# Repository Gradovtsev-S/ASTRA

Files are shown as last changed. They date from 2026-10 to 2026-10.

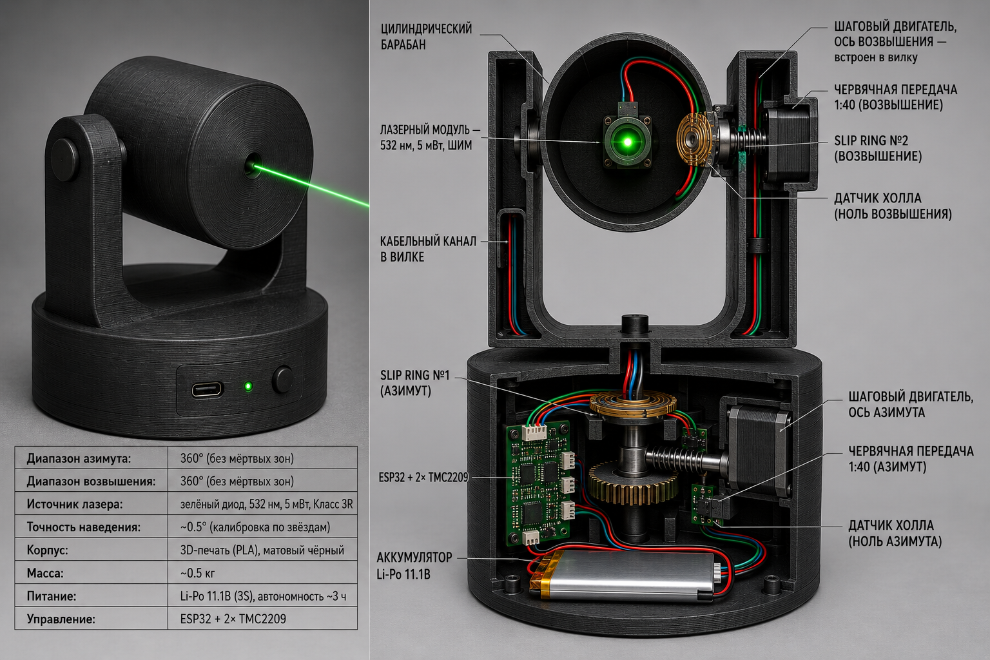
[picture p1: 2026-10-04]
docs/latex/laser_tracker.png

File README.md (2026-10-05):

# ASTRA

**Autonomous Stellar Targeting Remote-access Apparatus**

Репозиторий проекта **StarTracker** — автоматизированного лазерного звёздного трекера, который наводит зелёный лазер (532 нм, 5 мВт) на любую звезду, планету или иной небесный объект по команде из Telegram-бота.

> Проект выполняется в рамках курса «Введение в цифровое производство. Практикум цифрового производства», ФАКТ МФТИ, Долгопрудный, 2026.

---

## Команда

| Участник | Группа |
|---|---|
| Градовцев Святослав Алексеевич | Б03-503 |
| Коломоец Александр Анатольевич | Б03-503 |
| Минаева Полина Игоревна | Б03-502 |

---

## О проекте

Устройство на двухосной поворотной платформе определяет своё положение и ориентацию, рассчитывает положение небесного тела и наводит на него лазер. Управление — через Telegram-бот по Wi-Fi. Вся логика выполняется на одном микроконтроллере ESP32.

**Ключевые характеристики**

| Параметр | Значение |
|---|---|
| Диапазон азимута | 360° непрерывно |
| Диапазон возвышения | 360° непрерывно |
| Точность наведения | 0.5–2° |
| Лазер | зелёный 532 нм, 5 мВт, класс 3R |
| Управление | Telegram-бот |
| Автономность | 3 часа |
| Корпус | 3D-печать PLA/PETG + лазерная резка (фанера/акрил) |

**Элементная база:** ESP32, 2× TMC2209 StepStick, RTC DS3231, GPS Neoway G7A, IMU BMI160, магнитометр GY-511, 2× NEMA17, 2× токосъёмное кольцо (slip ring ∅12 мм, 6 каналов), 2× Li-Ion LP385590 (2300 мАч, 3S), DC-DC MP1584, лазерный модуль 5 мВт (TTL), MOSFET IRLZ44N, датчики Холла A3144E на LM393.

---

## Принцип работы

1. GPS и RTC дают положение установки и время UTC.
2. BMI160 измеряет наклон основания (крен и тангаж).
3. Магнитометр определяет направление нуля монтировки относительно севера (с поправкой на магнитное склонение).
4. По имени объекта рассчитываются его азимут и высота над горизонтом (Astronomy Engine, для звёзд — собственный каталог).
5. Углы переводятся в систему монтировки и отправляются на моторы.
6. Лазер включается только когда цель достигнута и все данные достоверны.

---

## Архитектура репозитория

```
ASTRA/
├── README.md
├── CONTRIBUTING.md
├── .gitignore
├── .gitattributes
│
├── CAD/                              # CAD-модели (SolidWorks)
│   └── Base/                         # Узел 1 — неподвижное основание
│       ├── Base.SLDPRT
│       ├── docs/
│       │   ├── StarTracker_Summary_v2.md     # Итоговый конструктив v2
│       │   └── StarTracker_DesignNotes.md    # Почему конструкция сделана именно так
│       └── simulation/               # Файлы расчёта прочности (SolidWorks Simulation)
│
├── docs/                             # Документация проекта
│   ├── project_proposal.md           # Цель, функционал, задачи, аналоги, элементная база
│   ├── project_plan.md               # Конструкция, схема соединений, распиновка ESP32,
│   │                                 #   алгоритмы, этапы, BOM, риски
│   ├── course_materials/             # Методические материалы курса
│   └── latex/                        # Проектное предложение в LaTeX (+ собранный PDF)
│
├── firmware/                         # Прошивка ESP32 (C/C++)
│   ├── platformio.ini                # Конфигурация PlatformIO
│   ├── data/
│   ├── src/
│   │   ├── config.h
│   │   ├── secrets.example.h         # Шаблон: копия секретов без значений
│   │   ├── secrets.h                 # Wi-Fi и токен Telegram (не коммитится)
│   │   ├── main.cpp                  # setup(): инициализация, loop(): главный цикл
│   │   │
│   │   ├── sensors/                  # Датчики
│   │   │   ├── gps.*                 # GPS Neoway G7A (UART) + RTC DS3231 (I2C)
│   │   │   ├── gyro_accel.*          # BMI160: крен и тангаж основания
│   │   │   └── mag_compass.*         # GY-511: истинный азимут нуля монтировки
│   │   │
│   │   ├── actuators/                # Исполнительные устройства
│   │   │   ├── motors.*              # 2× NEMA17 через TMC2209, поиск нуля по Холлу
│   │   │   └── laser.*               # Лазер с защитой по таймеру
│   │   │
│   │   └── logic/                    # Расчёт наведения
│   │       ├── handler.*             # Имя объекта + место/время/ориентация -> углы монтировки
│   │       ├── adapter.*             # Данные датчиков -> входные типы handler
│   │       ├── star_catalog.*        # Звёзды по имени -> RA/Dec (J2000)
│   │       └── astronomy.*           # Библиотека Astronomy Engine (не редактируется)
│   │
│   └── test/
│       └── motor_test.ino            # Тест шаговых двигателей
│
├── references/
│   └── modeling_links.txt            # Ссылки по креплению подшипников и ГОСТам на канавки
│
└── sketches/                         # Эскизы конструкции
```

### Описание разделов

| Папка | Назначение |
|---|---|
| **CAD** | CAD-модели механики по узлам. Рядом с моделью лежит документация с обоснованием решений и расчёты. |
| **docs** | Постановка задачи, план, анализ аналогов, BOM, риски. LaTeX-версия для оформления и сдачи. |
| **firmware** | Прошивка ESP32 и тестовые скетчи. |
| **references** | Ссылки и заметки, использованные при проектировании. |
| **sketches** | Эскизы конструкции. |

---

## Безопасность лазера

- после `laser_init` лазер выключен;
- включается только при `status == Ok`, достигнутой цели и достоверных данных датчиков;
- любая потеря данных выключает лазер;
- вторая линия защиты — автоотключение по таймеру `LASER_MAX_ON_MS` внутри `laser.cpp`.

---

## Используемые технологии

- **Железо:** ESP32, TMC2209, NEMA17, GPS Neoway G7A, BMI160, GY-511, DS3231
- **CAD:** SolidWorks
- **Прошивка:** C/C++, PlatformIO (Arduino framework для ESP32), Astronomy Engine
- **Интерфейс:** Telegram Bot API
- **Документация:** Markdown, LaTeX

---

## Сборка и запуск

1. Установить VS Code и расширение PlatformIO IDE, открыть папку `firmware`.
2. Скопировать `firmware/src/secrets.example.h` в `firmware/src/secrets.h`
   и вписать данные Wi-Fi и токен бота.
3. Заполнить значения в `firmware/src/config.h` (пины, механика, склонение).
4. Собрать (`pio run` или кнопка Build) и прошить ESP32.

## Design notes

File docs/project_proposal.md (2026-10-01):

# StarTracker

### Автоматизированный лазерный звёздный трекер

**Московский ордена Трудового Красного Знамени**  
**Физико-технический институт (Национальный исследовательский университет)**  
Факультет аэрофизики и космических исследований

Введение в цифровое производство. Практикум цифрового производства.

**Долгопрудный, 2026**

---

## Название проекта

**StarTracker** — автоматизированный лазерный звёздный трекер для наведения на небесные объекты.

---

## Ментор

Провоторов Павел Владимирович

---

## Команда

| Участник | Группа | Telegram | Телефон |
|---|---|---|---|
| Градовцев Святослав Алексеевич | Б03-504 | @svt_gradov | +7 999 248-86-97 |
| Коломоец Александр Анатольевич | Б03-504 | @AlexanderKolomoets | +7 961 213-93-21 |
| Минаева Полина Игоревна | Б03-504 | @Polina_Minaewa | +7 910 855-06-48 |

---

## Цель проекта

Создать автоматизированное устройство для наведения лазерного указателя (5 мВт, 532 нм) на любую звезду, планету или иной небесный объект по выбору пользователя, обеспечивающее полный охват небосвода по азимуту и возвышению (360° по каждой оси без мёртвых зон), автономную работу не менее 3 часов и точность наведения 0.5–2° после калибровки по звёздам, с управлением через Telegram-бот по Wi-Fi.

---

## Описание функционала

Компактный звёздный трекер на двухосной поворотной платформе. Устройство получает данные о местоположении пользователя через GPS-модуль, определяет ориентацию относительно горизонта при помощи гироскопа и акселерометра, и на основе астрономических расчётов наводит лазер на любой выбранный небесный объект.

### Основные функции

- Автоматическое определение координат пользователя (GPS NEO-6M)
- Определение угла наклона и ориентации устройства (IMU MPU-6050)
- Расчёт положения небесных тел в реальном времени (библиотека Astronomy Engine, C)
- Наведение лазера на выбранный объект по двум осям (азимут + возвышение, 360° каждая)
- Управление через Telegram-бот по Wi-Fi
- Калибровка устройства перед использованием (датчики Холла, процедура star alignment)

### Дополнительный функционал

- Режим автоматического сопровождения объекта (пересчёт позиции каждые 10 с)
- Встроенный каталог ~200 объектов во flash ESP32 + Yale Bright Star Catalog (9110 звёзд) в SPIFFS
- Ручной ввод координат как fallback при отсутствии GPS-сигнала
- RTC DS3231 для точного хранения времени при потере GPS

### Целевые характеристики

| Параметр | Значение |
|---|---|
| Диапазон азимута | 360° непрерывно (без мёртвых зон) |
| Диапазон возвышения | 360° непрерывно (через зенит) |
| Точность наведения | 0.5–2° (с калибровкой по звёздам) |
| Угловое разрешение | 0.0028°/шаг |
| Лазер | Зелёный 532 нм, 5 мВт, класс 3R |
| Управление | Telegram-бот по Wi-Fi (ESP32) |
| Питание | АКБ 3S Li-Ion 11.1В / 3000 мАч |
| Автономность | ≥ 3 часа |
| Масса | ~1.1–1.3 кг |
| Габариты | ~150×150×190 мм (цилиндр) + основание ∅220 мм |
| Корпус | 3D-печать PLA/PETG, матовый чёрный |

---

## Конструкция

### Форм-фактор
Цилиндрический корпус (~150×150×190 мм) на круглом основании (∅220 мм), установленный в U-рамку на поворотной платформе. Внешне напоминает PTZ-камеру на поворотной платформе.

### Две оси вращения

**Ось азимута (Z) — нижнее основание:**
- Диапазон: 360° непрерывно
- Привод: NEMA17 + червячная пара 1:40 (самоторможение)
- Slip Ring #1 в центре основания — передаёт питание и сигналы при любом угле

**Ось возвышения (Y) — горизонтальная ось U-рамки:**
- Диапазон: 360° непрерывно (цилиндр делает «сальто» через зенит)
- Привод: NEMA17 + червячная пара 1:40
- Slip Ring #2 в левой опоре — передаёт питание и сигнал к лазеру
- При переходе за 90° (зенит): платформа разворачивается на 180°, лазер идёт «за голову»

---

## Задачи проекта

1. Выбор элементной базы и архитектуры системы
2. Разработка CAD-моделей корпуса и поворотной платформы (SolidWorks)
3. Проектирование механизма наведения лазера (двухосная монтировка, червячные передачи)
4. Создание электронной схемы устройства
5. Разработка собственной печатной платы (KiCad, JLCPCB)
6. Интеграция GPS-модуля, гироскопа и управляющего контроллера
7. Разработка прошивки микроконтроллера (Arduino/ESP-IDF, Astronomy Engine)
8. Реализация Telegram-бота (`/find`, `/track`, `/stop`, `/calibrate`, `/status`)
9. Производство деталей методом 3D-печати и лазерной резки
10. Сборка и тестирование устройства
11. Калибровка системы и проверка точности наведения (star alignment по 2–3 звёздам)

---

## Анализ существующих аналогов

### 1. Celestron StarSense Explorer
Система использует смартфон для определения положения звёздного неба и помощи в наведении телескопа.

**Преимущества:** удобство использования, автоматический поиск объектов.  
**Недостатки:** высокая стоимость, необходимость использования телескопа, отсутствие лазерного наведения.  
https://www.celestron.com/pages/starsense-explorer

### 2. DIY OpenAstroTracker
Open-source проект автоматизированного трекера для астрофотографии на Arduino.

**Преимущества:** открытый исходный код, возможность самостоятельной сборки.  
**Недостатки:** сложность настройки, отсутствие удобного пользовательского интерфейса, не предназначен для лазерного наведения.  
https://openastrotech.com

**Отличие StarTracker от аналогов:** автономная работа с GPS и гироскопической системой, удобное управление через Telegram-бот, полный охват небосвода без мёртвых зон по обеим осям, компактный корпус с лазерным указателем вместо телескопической оптики.

---

## Эскиз проекта

Устройство состоит из цилиндрического корпуса с лазерным модулем, установленного в U-рамку на двухосной поворотной платформе. Нижнее основание содержит привод азимута и аккумулятор, U-рамка несёт привод возвышения и оба slip ring для непрерывного вращения по обеим осям.

*(Эскиз прилагается отдельным файлом)*

---

## Элементная база

| Компонент | Модель | Кол-во |
|---|---|---|
| Микроконтроллер | ESP32 DevKit v1 | 1 |
| Драйвер шаговых двигателей | TMC2209 StepStick | 2 |
| Шаговый двигатель | NEMA17, 40 мм, 1.8°/шаг | 2 |
| GPS-модуль | NEO-6M с антенной | 1 |
| Гироскоп и акселерометр | MPU-6050 (IMU, I2C) | 1 |
| Часы реального времени | DS3231 (RTC, I2C) | 1 |
| Лазерный модуль | Зелёный 532 нм, 5 мВт, TTL | 1 |
| MOSFET-ключ лазера | IRLZ44N | 2 |
| Токосъёмное кольцо | Slip Ring 12 мм, 6 каналов | 2 |
| Аккумулятор | 18650 Li-Ion 3S, 3000 мАч + BMS | 1 |
| DC-DC преобразователь | MP1584, 11.1В → 5В | 2 |
| Подшипники | 608ZZ | 4 |
| Датчики нулевого положения | Датчик Холла A3144 | 2 |
| Печатная плата | Заказная PCB (KiCad → JLCPCB) | 1 |
| Корпусные элементы | PLA/PETG, 3D-печать; фанера 4 мм, лазерная резка | — |

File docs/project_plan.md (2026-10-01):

# StarTracker — Итоговый план реализации

---

## Концепция устройства

**StarTracker** — автоматизированный лазерный звёздный трекер на двухосной монтировке.
Устройство наводит зелёный лазер (5 мВт) на любую звезду, планету или небесный объект
по выбору пользователя через Telegram-бот.

---

## Конструкция (финальный вариант)

### Форм-фактор
Цилиндрический корпус (~150×150×190 мм, масса ~1.1–1.3 кг) на круглом основании
(∅300 мм). Внешне напоминает PTZ-камеру / прожектор на поворотной платформе.

### Две оси вращения

**Ось азимута (Z) — нижнее основание:**
- Диапазон: 360° непрерывно
- Привод: NEMA17 + червячная пара 1:40 (самоторможение, не нужен удерживающий ток)
- Slip Ring #1 в центре основания — передаёт питание и сигналы наверх при любом угле

**Ось возвышения (Y) — горизонтальная ось U-рамки:**
- Диапазон: 360° непрерывно (цилиндр делает «сальто» через зенит)
- Привод: NEMA17 + червячная пара 1:40
- Slip Ring #2 в левой опоре — передаёт питание и сигнал к лазеру
- При переходе за 90° (зенит): платформа разворачивается на 180°, лазер идёт «за голову»

### Внутренняя компоновка цилиндра
| Компонент | Позиция | Примечание |
|---|---|---|
| Лазерный модуль 5 мВт | Передняя стенка | TTL-управление через MOSFET IRLZ44N |
| ESP32 + собственная PCB | Центр | Wi-Fi, управление всей системой |
| АКБ 3S Li-Ion 3000 мАч | Нижняя часть | ~3 часа автономной работы |
| GPS NEO-6M | Верхняя часть | Антенна выведена наружу или в крышку |
| IMU MPU-6050 | Рядом с PCB | I2C, коррекция наклона основания |
| RTC DS3231 | На PCB | Точное время при потере GPS |
| DC-DC конвертер | На PCB | 11.1В → 5В и 3.3В |

### U-рамка
Алюминий или PETG-печать. Две вертикальные стойки + поперечина сверху. В стойках —
подшипники оси возвышения. Крепится к поворотной платформе болтами.

### Корпус
- Цилиндр и основание: PLA/PETG, 3D-печать
- Элементы жёсткости: лазерная резка из фанеры 4 мм или акрила
- Крышка цилиндра: съёмная, на защёлках — для доступа к электронике

---

## Схема электрических соединений

### Питание (три уровня)
```
АКБ 3S Li-Ion (11.1В)
├── TMC2209 #1 VM (12В) — мотор азимута
├── TMC2209 #2 VM (12В) — мотор возвышения
└── DC-DC MP1584 → 5В
    ├── ESP32 (VIN)
    ├── Лазер (через MOSFET)
    └── ESP32 3V3 pin → MPU-6050, DS3231, датчики Холла
```

### Распиновка ESP32
| GPIO | Функция | Куда |
|---|---|---|
| GPIO16 | UART2 RX | GPS NEO-6M TX |
| GPIO17 | UART2 TX | GPS NEO-6M RX |
| GPIO21 | I2C SDA | MPU-6050 + DS3231 |
| GPIO22 | I2C SCL | MPU-6050 + DS3231 |
| GPIO2 | STEP | TMC2209 #1 (азимут) |
| GPIO4 | DIR | TMC2209 #1 (азимут) |
| GPIO5 | EN | TMC2209 #1 (азимут) |
| GPIO18 | STEP | TMC2209 #2 (возвышение) |
| GPIO19 | DIR | TMC2209 #2 (возвышение) |
| GPIO23 | EN | TMC2209 #2 (возвышение) |
| GPIO1 | UART0 TX | TMC2209 #1 и #2 PDN_UART (один провод, разные адреса) |
| GPIO25 | PWM/GPIO | Gate MOSFET IRLZ44N (лазер) |
| GPIO34 | Input | Датчик Холла — ноль азимута |
| GPIO35 | Input | Датчик Холла — ноль возвышения |

### Управление лазером
```
GPIO25 → резистор 1 кОм → Gate IRLZ44N
Source IRLZ44N → GND
Drain IRLZ44N → GND лазера
+5В → VCC лазера
```

---

## Математика и алгоритмы

### Астрорасчёт (библиотека Astronomy Engine, C)
```c
// Планеты:
astro_time_t t = Astronomy_MakeTime(year, month, day, hour, min, sec); // UTC!
astro_observer_t obs = Astronomy_MakeObserver(lat, lon, elev);
astro_equatorial_t eq = Astronomy_Equator(BODY_JUPITER, &t, &obs,
                                           EQUATOR_OF_DATE, ABERRATION);
astro_horizon_t hor = Astronomy_Horizon(&t, &obs, eq.ra, eq.dec, REFRACTION_NORMAL);
double az  = hor.azimuth;   // 0–360°, от севера
double alt = hor.altitude;  // градусы над горизонтом

// Звёзды из каталога:
astro_horizon_t hor = Astronomy_Horizon(&t, &obs,
    18.615,  // RA в часах (Вега)
    38.783,  // Dec в градусах
    REFRACTION_NORMAL);
```

### Коррекция наклона (IMU MPU-6050)
```c
// Углы наклона из акселерометра
float roll  = atan2(ay, az) * 180.0 / M_PI;
float pitch = atan2(-ax, sqrt(ay*ay + az*az)) * 180.0 / M_PI;

// Complementary filter (каждые 10 мс)
roll  = 0.98 * (roll  + gx * 0.01) + 0.02 * atan2(ay, az) * 180.0 / M_PI;
pitch = 0.98 * (pitch + gy * 0.01) + 0.02 * atan2(-ax, ...) * 180.0 / M_PI;

// Поворот вектора для компенсации наклона
double x = cos(alt_r) * sin(az_r);
double y = cos(alt_r) * cos(az_r);
double z = sin(alt_r);
// ... вращение через матрицы крена и тангажа ...
double az_corr  = atan2(x2, y1) * 180.0 / M_PI;
double alt_corr = asin(z2)      * 180.0 / M_PI;
```

### Логика 360° по возвышению
```c
// Если объект «за зенитом» — цилиндр делает сальто
if (alt_target > 90.0) {
    alt_motor = 180.0 - alt_target; // лазер смотрит назад
    az_motor  = az_target + 180.0;  // платформа разворачивается
    if (az_motor >= 360.0) az_motor -= 360.0;
} else {
    alt_motor = alt_target;
    az_motor  = az_target;
}
```

### Перевод углов в шаги моторов
```c
// NEMA17 (200 шаг/об) + червяк 1:40 + микрошаг ×16
// Итого: 200 × 40 × 16 = 128 000 шагов/оборот
// Разрешение: 360° / 128000 = 0.0028°/шаг

int az_steps  = (az_motor  / 360.0) * 128000;
int alt_steps = (alt_motor / 360.0) * 128000;
stepper_az.moveTo(az_steps);
stepper_alt.moveTo(alt_steps);
```

---

## Каталог звёзд (встроен во flash ESP32)

```c
typedef struct { const char* name; double ra; double dec; } StarEntry;

const StarEntry catalog[] = {
    {"Vega",        18.615,  38.783},
    {"Sirius",       6.752, -16.716},
    {"Arcturus",    14.261,  19.182},
    {"Betelgeuse",   5.920,   7.407},
    {"Rigel",        5.242,  -8.202},
    {"Capella",      5.278,  45.998},
    {"Aldebaran",    4.599,  16.509},
    {"Spica",       13.420, -11.161},
    {"Antares",     16.490, -26.432},
    {"Polaris",      2.530,  89.264},
    // ... до ~200 объектов — занимает ~10 КБ flash
};
```
Полный Yale Bright Star Catalog (9110 звёзд) в бинарном виде — ~400 КБ, хранится в SPIFFS.

---

## Поэтапный план реализации

### Этап 1 — Компоненты и тестовый стенд (4–5 недель)
- [ ] Заказать: ESP32, NEO-6M, MPU-6050, DS3231, 2× NEMA17, 2× TMC2209, IRLZ44N, лазер 5 мВт TTL, 2× slip ring (∅12–22 мм), подшипники, АКБ 3S
- [ ] Собрать на breadboard: ESP32 + IMU + GPS
- [ ] Проверить библиотеку Astronomy Engine — точность расчётов по известным объектам
- [ ] Написать базовый complementary filter для IMU
- [ ] Проверить управление лазером через MOSFET

### Этап 2 — Механика (4–5 недель)
- [ ] CAD-модель в Fusion 360 / FreeCAD:
  - круглое основание с червячной парой азимута и slip ring #1
  - U-рамка с подшипниками и slip ring #2 на оси возвышения
  - цилиндрический корпус с креплением под ось возвышения
- [ ] 3D-печать деталей (PLA для прототипа, PETG для финала)
- [ ] Лазерная резка жёстких элементов
- [ ] Сборка и проверка плавности хода обеих осей
- [ ] Проверка самоторможения червячных пар

### Этап 3 — Электроника (3–4 недели)
- [ ] Схема в KiCad: ESP32 + 2× TMC2209 + GPS + IMU + RTC + MOSFET + DC-DC
- [ ] Развести PCB (2-слойная, ~80×60 мм)
- [ ] Заказать изготовление платы (JLCPCB / PCBWay)
- [ ] Пайка и проверка
- [ ] Интеграция slip ring в обе оси, прокладка кабелей

### Этап 4 — Прошивка (5–6 недель)
- [ ] Инициализация периферии (GPS, IMU, моторы, лазер)
- [ ] Процедура калибровки нуля (уход на концевые выключатели Холла)
- [ ] Процедура калибровки IMU при включении (500 замеров, вычет bias)
- [ ] Астрорасчёты (Astronomy Engine) + коррекция наклона
- [ ] Управление моторами (AccelStepper / TMCStepper)
- [ ] Telegram-бот: `/find <объект>`, `/track`, `/stop`, `/calibrate`, `/status`
- [ ] Режим слежения: пересчёт позиции каждые 10 с

### Этап 5 — Интеграция и тестирование (3–4 недели)
- [ ] Сборка полного прототипа
- [ ] Дневные тесты: наведение на Луну, Солнце (с фильтром!), яркие планеты
- [ ] Ночные тесты: проверка точности по известным звёздам
- [ ] Калибровка star alignment (выравнивание по 2–3 звёздам для устранения систематики)
- [ ] Измерение реальной точности наведения

---

## Список компонентов (BOM)

| Компонент | Кол-во | Примерная цена |
|---|---|---|
| ESP32 DevKit | 1 | ~400 руб |
| NEMA17 (40 мм) | 2 | ~600 руб × 2 |
| TMC2209 StepStick | 2 | ~400 руб × 2 |
| GPS NEO-6M с антенной | 1 | ~500 руб |
| IMU MPU-6050 | 1 | ~150 руб |
| RTC DS3231 | 1 | ~200 руб |
| Лазер зелёный 5 мВт TTL | 1 | ~300 руб |
| MOSFET IRLZ44N | 2 | ~50 руб × 2 |
| Slip Ring 12 мм (6 каналов) | 2 | ~400 руб × 2 |
| АКБ 18650 × 3 + холдер | 1 | ~700 руб |
| DC-DC MP1584 модуль | 2 | ~100 руб × 2 |
| Подшипники 608ZZ | 4 | ~80 руб × 4 |
| Датчики Холла A3144 | 2 | ~50 руб × 2 |
| PCB заказная (JLCPCB) | 1 | ~500 руб |
| PLA/PETG пластик ~0.5 кг | — | ~600 руб |
| Крепёж, провода, разъёмы | — | ~500 руб |
| **ИТОГО** | | **~7 300 руб** |

---

## Ключевые риски и митигация

| Риск | Митигация |
|---|---|
| Люфт в червячной паре → ошибка наведения | Двусторонняя выборка люфта, подходить к цели всегда с одной стороны |
| Дрейф IMU при долгой работе | Complementary filter + периодическая рекалибровка |
| Закрутка кабелей при 360° ALT | Slip Ring #2 на оси возвышения |
| GPS не берёт сигнал в помещении | Ручной ввод координат как fallback через Telegram-бот |
| Нагрев TMC2209 | StealthChop режим + снижение тока удержания до 30% при простое |
| Лазер не попадает в цель у зенита | Логика 360° ALT: сальто + разворот платформы на 180° |

---

## Характеристики финального устройства

| Параметр | Значение |
|---|---|
| Диапазон азимута | 360° непрерывно |
| Диапазон возвышения | 360° непрерывно (через зенит) |
| Точность наведения | 0.5–2° (с star alignment) |
| Угловое разрешение | 0.0028°/шаг |
| Автономность | ≥ 3 часа |
| Масса | ~1.1–1.3 кг |
| Габариты | ~150×150×190 мм (цилиндр) + основание ∅300 мм |
| Лазер | Зелёный 532 нм, 5 мВт, класс 3R |
| Управление | Telegram-бот по Wi-Fi |
| Питание | АКБ 3S Li-Ion 11.1В / 3000 мАч |

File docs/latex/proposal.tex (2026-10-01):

\documentclass[12pt, a4paper]{article}

\usepackage{fontspec}
\usepackage{polyglossia}
\usepackage{graphicx}
\setmainlanguage{russian}
\setotherlanguage{english}
\setmainfont{DejaVu Serif}
\setsansfont{DejaVu Sans}
\setmonofont{DejaVu Sans Mono}

\usepackage[left=25mm, right=20mm, top=20mm, bottom=20mm]{geometry}
\usepackage{booktabs}
\usepackage{tabularx}
\usepackage{array}
\usepackage{hyperref}
\usepackage{parskip}
\usepackage{enumitem}
\usepackage{titlesec}

\hypersetup{
    colorlinks=true,
    linkcolor=black,
    urlcolor=blue
}

\titleformat{\section}{\large\bfseries}{}{0em}{}[\titlerule]
\titleformat{\subsection}{\normalsize\bfseries}{}{0em}{}

\setlength{\parindent}{0pt}
\setlength{\parskip}{6pt}

\begin{document}

% =================== ТИТУЛЬНЫЙ ЛИСТ ===================
\thispagestyle{empty}

\begin{center}

{\small
Московский ордена Трудового Красного Знамени\\
Физико-технический институт\\
(Национальный исследовательский университет)\\
Факультет аэрофизики и космических исследований
}

\vspace{1cm}

\vfill

{\Huge\bfseries ASTRA}

\vspace{0.5cm}

{\Large Автоматизированный лазерный звёздный трекер}

\vspace{0.5cm}

{\normalsize Проектное предложение}

\vfill

{\small Долгопрудный, 2026}

\end{center}

\newpage

% =================== ОСНОВНОЕ СОДЕРЖАНИЕ ===================
\setcounter{page}{1}

\section*{Название проекта}

\textbf{ASTRA} (Autonomous Stellar Targeting Remote-Access Apparatus) --- автоматизированный лазерный звёздный трекер для наведения на небесные объекты.

\section*{Ментор}

Провоторов Павел Владимирович

\section*{Команда}

\begin{tabularx}{\textwidth}{|X|c|c|c|}
\hline
\textbf{Участник} & \textbf{Группа} & \textbf{Telegram} & \textbf{Телефон} \\
\hline
Градовцев Святослав Алексеевич & Б03-503 & @svt\_gradov & +7~999~248-86-97 \\
\hline
Коломоец Александр Анатольевич & Б03-503 & @AlexanderKolomoets & +7~961~213-93-21 \\
\hline
Минаева Полина Игоревна & Б03-502 & @Polina\_Minaewa & +7~910~855-06-48 \\
\hline
\end{tabularx}

\section*{Цель проекта}

Создать автоматизированное устройство для наведения лазерного указателя (5~мВт, 532~нм) на любую звезду, планету или иной небесный объект по выбору пользователя, обеспечивающее полный охват небосвода по азимуту и возвышению (360° по каждой оси без мёртвых зон), автономную работу не менее 3~часов и точность наведения 0{,}5--2° после калибровки по звёздам, с управлением через Telegram-бот по Wi-Fi.

\section*{Описание функционала}

Компактный звёздный трекер на двухосной поворотной платформе. Устройство получает данные о местоположении пользователя через GPS-модуль, определяет ориентацию относительно горизонта при помощи гироскопа и акселерометра, и на основе астрономических расчётов наводит лазер на любой выбранный небесный объект.

\subsection*{Основные функции}

\begin{itemize}[leftmargin=*, nosep]
    \item Автоматическое определение координат пользователя (GPS NEO-6M)
    \item Определение угла наклона и ориентации устройства (IMU MPU-6050)
    \item Расчёт положения небесных тел в реальном времени
    \item Наведение лазера на выбранный объект по двум осям
    \item Управление через Telegram-бот по Wi-Fi
    \item Калибровка устройства перед использованием (датчики Холла, процедура star alignment)
\end{itemize}

\subsection*{Дополнительный функционал}

\begin{itemize}[leftmargin=*, nosep]
    \item Режим автоматического сопровождения объекта
    \item Встроенный каталог {\textasciitilde}200 объектов во flash ESP32 + Yale Bright Star Catalog (9110~звёзд) в SPIFFS
    \item Ручной ввод координат как fallback при отсутствии GPS-сигнала
    \item RTC DS3231 для точного хранения времени при потере GPS
\end{itemize}

\subsection*{Целевые характеристики}

\begin{tabularx}{\textwidth}{|X|X|}
\hline
\textbf{Параметр} & \textbf{Значение} \\
\hline
Диапазон азимута & 360° непрерывно \\
\hline
Диапазон возвышения & 360° непрерывно \\
\hline
Точность наведения & 0{,}5--2°  \\
\hline
Угловое разрешение & 0{,}0028°/шаг \\
\hline
Лазер & Зелёный 532~нм, 5~мВт, класс 3R \\
\hline
Управление & Telegram-бот по Wi-Fi (ESP32) \\
\hline
Питание & АКБ 3S Li-Ion 11{,}1~В / 3000~мАч \\
\hline
Автономность & 3 часа \\
\hline
Масса & {\textasciitilde}1{,}1--1{,}3~кг \\
\hline
Габариты & {\textasciitilde}150$\times$150$\times$190~мм (цилиндр) + основание Ø220~мм \\
\hline
Корпус & 3D-печать PLA/PETG \\
\hline
\end{tabularx}

\section*{Конструкция}

\subsection*{Форм-фактор}

Цилиндрический корпус ({\textasciitilde}150$\times$150$\times$190~мм) на круглом основании (Ø220~мм), установленный в U-рамку на поворотной платформе.

\subsection*{Две оси вращения}

\textbf{Ось азимута --- нижнее основание:}
\begin{itemize}[leftmargin=*, nosep]
    \item Диапазон: 360° непрерывно
    \item Привод: NEMA17 + червячная пара 1:40
    \item Slip Ring \#1 в центре основания --- передаёт питание и сигналы при любом угле вращения
\end{itemize}

\textbf{Ось возвышения --- горизонтальная ось U-рамки:}
\begin{itemize}[leftmargin=*, nosep]
    \item Диапазон: 360° непрерывно
    \item Привод: NEMA17 + червячная пара 1:40
    \item Slip Ring \#2 в одной из опор --- передаёт питание и сигнал к лазеру
\end{itemize}

\section*{Задачи проекта}

\begin{enumerate}[leftmargin=*, nosep]
    \item Выбор элементной базы и архитектуры системы
    \item Разработка CAD-моделей корпуса и поворотной платформы (SolidWorks)
    \item Проектирование механизма наведения лазера (двухосная монтировка, червячные передачи)
    \item Создание электронной схемы устройства
    \item Разработка собственной печатной платы
    \item Интеграция GPS-модуля, гироскопа и управляющего контроллера
    \item Разработка прошивки микроконтроллера
    \item Реализация Telegram-бота
    \item Производство деталей методом 3D-печати и лазерной резки
    \item Сборка и тестирование устройства
    \item Калибровка системы и проверка точности наведения
\end{enumerate}

\section*{Анализ существующих аналогов}

\subsection*{1. Celestron NexStar SE (серия GoTo-телескопов)}

Линейка автоматизированных телескопов с computerized GoTo-монтировкой. 
Устройство автоматически наводится на выбранный объект из базы данных 
40\,000+ небесных тел и удерживает его в поле зрения. Выравнивание 
выполняется по технологии SkyAlign --- достаточно навестись на любые 
три ярких объекта.

\textbf{Преимущества:} полностью автоматическое наведение и сопровождение 
объектов, большая база данных, простое выравнивание, высокая точность 
червячных приводов.\\
\textbf{Недостатки:} очень высокая стоимость (от \$500), большие габариты 
и масса (требует штатива), необходимость телескопической оптики, 
отсутствие лазерного указателя для визуального наблюдения без окуляра.\\
\url{https://www.celestron.com/products/nexstar-5se-computerized-telescope}

\subsection*{2. DIY OpenAstroTracker}

Open-source проект монтировки для астрофотографии на Arduino. Устройство компенсирует вращение Земли, удерживая телескоп или камеру на выбранном объекте, однако не осуществляет автоматического наведения — ориентация выполняется вручную с выравниванием по Полярной звезде.

\textbf{Преимущества:} открытый исходный код, возможность самостоятельной сборки, низкая стоимость.\\
\textbf{Недостатки:} отсутствие автоматического наведения на объект, необходимость ручной полярной юстировки, наличие мёртвых зон по углу возвышения, не предназначен для лазерного указания.\\
\url{https://openastrotech.com}

\textbf{Отличие ASTRA от аналогов:} автономная работа с GPS и гироскопической системой, удобное управление через Telegram-бот, полный охват небосвода без мёртвых зон по обеим осям, компактный корпус с лазерным указателем вместо телескопической оптики.

\section*{Эскиз проекта}

Устройство состоит из цилиндрического корпуса с лазерным модулем, установленного в U-рамку на поворотной платформе. Нижнее основание содержит привод азимута и аккумулятор, U-рамка несёт привод возвышения и оба slip ring для непрерывного вращения по обеим осям.

\begin{figure}[h]
    \centering
    
    \caption{Эскиз устройства ASTRA}
\end{figure}

\section*{Элементная база}

\begin{tabularx}{\textwidth}{|X|X|c|}
\hline
\textbf{Компонент} & \textbf{Модель} & \textbf{Кол-во} \\
\hline
Микроконтроллер & ESP32 DevKit v1 & 1 \\
\hline
Драйвер шаговых двигателей & TMC2209 StepStick & 2 \\
\hline
Шаговый двигатель & NEMA17, 40~мм, 1{,}8°/шаг & 2 \\
\hline
GPS-модуль & NEO-6M с антенной & 1 \\
\hline
Гироскоп и акселерометр & MPU-6050 (IMU, I2C) & 1 \\
\hline
Часы реального времени & DS3231 (RTC, I2C) & 1 \\
\hline
Лазерный модуль & Зелёный 532~нм, 5~мВт, TTL & 1 \\
\hline
MOSFET-ключ лазера & IRLZ44N & 2 \\
\hline
Токосъёмное кольцо & Slip Ring 12~мм, 6~каналов & 2 \\
\hline
Аккумулятор & 18650 Li-Ion 3S, 3000~мАч + BMS & 1 \\
\hline
DC-DC преобразователь & MP1584, 11{,}1~В $\to$ 5~В & 2 \\
\hline
Подшипники & 608ZZ & 4 \\
\hline
Датчики нулевого положения & Датчик Холла A3144 & 2 \\
\hline
Печатная плата & Заказная PCB (KiCad $\to$ JLCPCB) & 1 \\
\hline
Корпусные элементы & PLA/PETG, 3D-печать, лазерная резка & --- \\
\hline
\end{tabularx}

\end{document}

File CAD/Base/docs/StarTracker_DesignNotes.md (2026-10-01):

# StarTracker — Пояснения к конструктивным решениям

Этот документ объясняет **почему** размеры и узлы сделаны именно так, а не просто перечисляет цифры. Читать вместе с `StarTracker_Summary_v2.md`.

---

## 1. Почему на вертикальном валу — один подшипник, а на горизонтальных — два

**Правило:** количество подшипников на валу зависит от того, несёт ли сам вал изгибающий момент (опрокидывающую нагрузку) или нет.

- **Вертикальный вал (азимут):** вал сам по себе нагрузки не несёт — ни осевой (вес всей верхней части), ни радиальной (боковые усилия при движении). Всё это забирают на себя **ролики поворотной платформы**, работающие на большом радиусе (70 мм) и потому создающие большое плечо для сопротивления опрокидыванию. Вал в этой схеме — только передатчик крутящего момента от червячного колеса. Одного подшипника достаточно, чтобы центрировать вал; второй не добавит жёсткости, потому что момент гасится не валом.

- **Горизонтальные валы (возвышение в вилке, вал в цилиндре):** здесь вал **консольно** несёт вес (цилиндр с лазером висит на конце), создавая реальный изгибающий момент. Один подшипник такую нагрузку не удержит — конец вала будет «клевать» под весом. Нужны **два подшипника**, разнесённые максимально далеко друг от друга (в вилке — 120 мм между стойками, в цилиндре — ~132 мм) — чем больше база между опорами, тем меньше люфт на конце от момента.

**Общий принцип:** если нагрузка на вал только крутящий момент — 1 опора. Если есть консольный изгиб — минимум 2 опоры, разнесённые как можно дальше.

---

## 2. Почему ролики платформы — 3 штуки, а не 6

Изначально закладывалось 6 роликов через 60°. Причина отказа — **геометрия, а не прочность**.

- **Любые 3 точки опоры всегда лежат в одной плоскости** — это математический факт (как трёхногий табурет никогда не шатается, даже на неровном полу).
- **4 и более точек** — это уже переопределённая система: если реальная поверхность (напечатанная на 3D-принтере, с неизбежными микро-неровностями) не идеально плоская, часть точек **физически не будет касаться** платформы. Вся нагрузка ляжет на 3-4 ролика, которые случайно оказались чуть выше остальных — оставшиеся будут просто холостыми, что не даёт никакого выигрыша по сравнению с честными тремя, зато усложняет конструкцию.

**Вывод:** для FDM-печати без последующей механической калибровки/шлифовки посадочных поверхностей — 3 ролика через 120° это единственная схема, гарантирующая полный контакт всех точек опоры без постобработки. Расчёт нагрузки (~450 г на ролик при общем весе подвижной части ~1.3-1.4 кг) показывает, что подшипники 625ZZ и с тремя точками имеют огромный запас прочности (грузоподъёмность подшипника на 2-3 порядка выше фактической нагрузки) — переход на 3 ролика ничем не жертвует по несущей способности.

---

## 3. Почему ролики стоят на радиальной горизонтальной оси, а не на вертикальном «пеньке»

Первая идея — вертикальная ось, торчащая вверх из основания, ролик просто надет на неё как шайба. Проблема: в такой ориентации **ролик катится боковой (торцевой) поверхностью**, а не беговой дорожкой — то есть подшипник работал бы не по назначению, силы шли бы не через тела качения, а через уплотнения/сепаратор, что быстро выведет его из строя.

**Решение — радиальная горизонтальная ось** (направлена от края платформы к центру, как спица). В этой ориентации ролик стоит «диском» и катится **верхней точкой наружного кольца** по нижней плоскости подвижной платформы — классическая схема поворотного стола (lazy susan). Именно так подшипник нагружается радиально, как и задумано производителем.

---

## 4. Почему ось ролика консольная (растёт из одной стенки), а не мост между двумя стенками

Мост между двумя стенками (ось, опёртая с обеих сторон) прочнее на изгиб, чем консоль — но здесь важнее удобство сборки:

- При мосте подшипник пришлось бы либо запрессовывать вдоль всей длины оси при печати заодно с ней (нереализуемо — вал печатается внутри, подшипник нужно надевать после печати), либо печатать мост и вал раздельно с последующей сборкой в очень стеснённом пространстве.
- При консольной оси (растёт из внутренней, обращённой к центру стенки пилона) ролик надевается **сбоку**, свободно, без изгибания под углом — после чего конструкция «запирается» разъёмным колпачком снаружи, который берёт на себя роль второй опоры.

Чтобы компенсировать меньшую жёсткость консоли, у основания оси сделан **не тонкий стержень, а массивный асимметричный прилив** (см. следующий пункт) — по сути, это гибрид: с точки зрения сборки — консоль, с точки зрения прочности в критичном сечении (у корня) — почти как жёстко заделанная балка.

---

## 5. Почему переход «вал → тело пилона» сделан асимметричным приливом, а не симметричным конусом

Классическое решение для снятия концентрации напряжений — симметричный конус (галтель по всей окружности). Проблема в данном случае — **геометрическое ограничение сверху**: центр оси стоит на 3.2 мм ниже верхней плоскости платформы (иначе ролик не поместится под платформу с нужным зазором), а радиус самого вала — 2.5 мм. Это оставляет только **0.7 мм запаса вверх** до потолка (уровня платформы) — симметричный конус, ограниченный этим потолком со всех сторон, получился бы максимум ∅6.4 мм у основания, что даёт довольно слабое усиление.

**Решение:** сделать переход несимметричным — **плоский срез сверху** (вровень с потолком, там где расширяться некуда), а **вниз и по бокам расширять свободно** (там места достаточно, до границ самого пилона). В сечении такой переход похож на клин/каплю со срезанной верхушкой.

Это даёт кратно большую площадь поперечного сечения в критичной зоне (у корня оси) по сравнению с симметричным конусом, не будучи ограниченным потолком — то есть используется всё доступное пространство, а не только то немногое, что осталось бы при симметрии.

**Про угол раскрытия:** важно не увлекаться шириной основания при короткой длине перехода — избыточно широкое основание на короткой длине даёт слишком острый угол (близкий к 90° от оси), что само по себе становится концентратором напряжений и плохо печатается (нависание требует поддержек). Разумный угол раскрытия — **30-45°** от оси вала; при длине перехода 3-4 мм это даёт диаметр основания порядка **10-12 мм** — оптимальный компромисс между прочностью, печатаемостью и компактностью.

---

## 6. Зачем нужен «монтажный зазор» в 6 мм за концом оси ролика

Подшипник 625ZZ имеет наружный диаметр 16 мм, а вал под него — всего 5 мм. Чтобы надеть подшипник на вал, его нужно сначала завести под небольшим углом/сбоку (обойти торец стенки пилона), а затем сдвинуть вдоль оси на посадочное место — «в притык» без запаса это физически неудобно или невозможно в тесном вырезе.

6 мм свободного пространства **за концом рабочей части оси** — это зона манёвра для такого движения при сборке. После сборки это пространство ничем не занято (кроме колпачка снаружи) — оно не несёт нагрузки, только облегчает монтаж.

---

## 7. Зачем зазор перед канавкой под стопорное кольцо (и почему потом от него отказались)

Изначально закладывался зазор 0.3 мм между торцом подшипника и канавкой под стопорное кольцо — расчёт был на то, что при неточной печати кольцо может **поджать** внутреннее кольцо подшипника слишком туго (преднатяг), увеличивая трение.

После уточнения задачи (StarTracker — прибор точного наведения, паразитный люфт в звене недопустим) решение изменено: **зазор убран**, канавка располагается сразу впритык к подшипнику. Стопорное кольцо (E-clip) обладает небольшой собственной упругостью и само компенсирует небольшую разницу размеров, слегка поджимая кольцо и устраняя осевой люфт, не создавая при этом жёсткого преднатяга (в отличие, например, от гайки). Итоговая точность/люфт калибруется опытным путём на конкретном принтере (тестовая печать + замер реальной усадки).

---

## 8. Почему колпачок ролика — две половины, а не сплошная деталь с отверстием

Первый вариант — сплошной колпачок с глухим отверстием, надеваемый вдоль оси. Проблема — при трёх пилонах, стоящих близко друг к другу под платформой, часто физически негде «подлезть» точно вдоль оси, чтобы надеть колпачок после сборки ролика и стопорного кольца.

**Решение — разъём по горизонтали**, две симметричные половины (сверху и снизу), каждая — полукруглый жёлоб. Половины подводятся к валу не вдоль оси, а перпендикулярно (сверху и снизу), что удобно в стеснённом пространстве, а затем стягиваются винтами друг с другом.

**Важная деталь:** в месте, где сидит стопорное кольцо (E-clip, наружный диаметр ~11 мм), жёлоб колпачка сделан **уже** (∅9-10 мм) — то есть кольцо физически не может провалиться в эту полость и вылезти в сторону, оно зажато между канавкой на валу и стенкой колпачка.

---

## 9. Почему наружные кольца подшипников 6001 теперь фиксируются стопорным кольцом, а не уголками

Уголки (`Bracket_Corner`) требовали печати мелких дополнительных деталей и точной установки нескольких винтов на каждый подшипник (3-4 шт), с риском задеть вращающуюся часть при неточном изготовлении.

**Стопорное кольцо**, врезанное прямо в стенку посадочного отверстия (без расширения диаметра — канавка режется в той же толщине стенки, что и основная посадка), даёт тот же результат — торцевой упор для наружного кольца — но:
- меньше деталей для печати и сборки;
- не требует резьбы в тонких стенках;
- радиальную фиксацию (от проворота наружного кольца в отверстии) обеспечивает тонкий слой клея-фиксатора для подшипников, что снимает необходимость в точном натяге при печати (посадка делается чуть свободнее — ∅28.1-28.2 мм вместо жёсткого натяга, снижая риск раскола пластика).

---

## 10. Лабиринтные уплотнения — зачем и как работают

В проекте два места с лабиринтным уплотнением:

1. **Между валом и верхней стенкой основания** (ниже подшипника): сужение канала до ∅12.2 мм на глубину 7 мм. Это не несущий элемент и не полноценное уплотнение (как резиновый сальник), а **пылевой барьер**: узкий длинный зазор создаёт извилистый путь, через который пыли/мелкому мусору сложнее попасть внутрь корпуса к подшипнику и электронике, при этом сам вал не касается стенок (нет трения, нет дополнительного износа).

2. **Между платформой и основанием** (по контуру): выступ платформы (∅160/∅150 мм, высота 6 мм) входит в канавку верхней стенки основания (ширина 6 мм, глубина 5 мм). Та же логика — не контактное уплотнение, а геометрический барьер против попадания воды/пыли в стык между вращающимися деталями, без трения, которое создавало бы сопротивление вращению по азимуту.

**Общий принцип лабиринтных уплотнений:** защита без контакта. В отличие от резиновых уплотнений/сальников, здесь нет трения и износа, но и герметичность неполная — этого достаточно для защиты от пыли и брызг, но не для полного погружения в воду.

---

## 11. Центральная втулка (посадка подшипника вертикального вала) — почему высота больше ширины подшипника

Правило: глубина посадочного гнезда = ширина подшипника + запас, а не «впритык».

Для 6001 (ширина 8 мм) — глубина гнезда 9 мм, плюс канавка под стопорное кольцо (1.2-1.4 мм) в той же стенке — итог ~10.2-10.4 мм. Запас нужен, чтобы:
- скомпенсировать погрешность печати по высоте (усадка, точность слоя) — без запаса подшипник может либо не дойти до дна, либо, наоборот, «зависнуть», не достигнув упора по диаметру;
- гарантировать, что подшипник упирается именно в диаметральный буртик (боковой упор), а не в дно гнезда раньше времени;
- вместить канавку под стопорное кольцо без пересечения с посадочной зоной самого подшипника.

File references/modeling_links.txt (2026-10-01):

1)крепление подшипников
https://impod.ru/article/95-fiksaciya-podshipnikov - общее, легкое
https://www.snr.com.ru/e/fixing_bearings_1.htm - побольше, посложнее
https://www.hydro-pnevmo.ru/topic.php?ID=164 - госты для канавок наружного и внутреннего

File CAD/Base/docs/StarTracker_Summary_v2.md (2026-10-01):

# StarTracker — Итоговый конструктив v2 (обновлённая сводка)

> Обновления относительно первой версии: узел роликов поворотной платформы полностью переработан (6× 623ZZ на вертикальных пеньках → 3× 625ZZ на радиальных консольных осях), способ фиксации наружных колец подшипников 6001 изменён (уголки/диск → стопорные кольца + клей). Остальные узлы — без изменений.

---

## Концепция устройства

**StarTracker** — автоматизированный лазерный звёздный трекер на двухосной монтировке. Наводит зелёный лазер (5 мВт, 532 нм) на любую звезду, планету или небесный объект через Telegram-бот по Wi-Fi. Управляющий микроконтроллер — ESP32.

## Общая механическая схема

Три основных узла: **основание** (неподвижное) → **поворотная платформа** (вращается по азимуту) → **вилка** (крепится к платформе) → **цилиндр с лазером** (вращается по возвышению).

---

## УЗЕЛ 1 — ОСНОВАНИЕ

### Конструкция корпуса
- Цилиндрическая коробка, глухая снизу и сверху — монолитная деталь
- Внешний диаметр: ∅160 мм, высота 105 мм, толщина стенок 4 мм
- Верхняя стенка: 7 мм + посадка подшипника
- Скругление внешних углов R5 мм

### Вертикальный вал (ось азимута)
- Материал: пластик (3D-печать), диаметр ∅12 мм, длина ~130 мм
- Внутренний канал под провода: 5×5 мм по всей длине
- Стопорные винты М3 — фиксация червячного колеса и платформы

### Подшипник вертикального вала — **1 шт, без изменений**
- Тип: 6001 (∅28/∅12×8 мм), в верхней стенке основания
- **Вал не несёт осевой/радиальной нагрузки — только крутящий момент.** Второй подшипник не требуется: опрокидывающий момент от веса вилки+цилиндра гасится роликами платформы на радиусе 70 мм, а не валом. См. `StarTracker_DesignNotes.md`, раздел «Один подшипник vs два».

### Фиксация наружного кольца подшипника 6001 — **новый стандарт для всех 5 подшипников 6001 в проекте**
- Посадочное отверстие: ∅28.1–28.2 мм (посадка с небольшим зазором, не тугой натяг — риск раскола пластика при запрессовке)
- С одной стороны — буртик/уступ в теле детали (осевой упор)
- С другой стороны — **проточка под стопорное кольцо** прямо в той же стенке (без расширения всего отверстия): ГОСТ 13943-86 / DIN 472 аналог для ∅28 мм — диаметр канавки ∅29.4–29.6 мм, ширина паза 1.2–1.4 мм
- Радиальная фиксация / защита от проворота: тонкий слой резьбового фиксатора для подшипников (Loctite 603/648 или аналог) на наружное кольцо перед установкой
- **Высота посадочной втулки (пример — верхняя стенка основания):** 9 мм (8 мм ширина подшипника + 1 мм запас) + 1.2–1.4 мм (ширина канавки, врезанной в ту же стенку, без прироста диаметра) ≈ **10.2–10.4 мм общая глубина**
- Этот метод заменяет уголки (`Bracket_Corner`) и диск (`Bracket_Disk`) из первой версии проекта во всех 5 местах установки 6001: верхняя стенка основания, левая и правая стойки вилки, передний торец и задняя крышка цилиндра

### Привод азимута
- Мотор NEMA17, червяк модуль 1, червячное колесо ∅80 мм / 40 зубьев — передаточное отношение 1:40

### Датчик Холла азимута, Slip Ring #1 — без изменений (см. исходную сводку)

### УЗЕЛ РОЛИКОВ ПОВОРОТНОЙ ПЛАТФОРМЫ — **полностью переработан**

**Количество и тип:**
- **3× подшипника 625ZZ** (∅16/∅5×5 мм), расположены через **120°** на радиусе 70 мм от центра
- Причина замены 6× 623ZZ → 3× 625ZZ: статическая определённость (3 точки всегда лежат в одной плоскости независимо от точности печати; при 6 точках часть роликов гарантированно не касается платформы). Подробности — в `StarTracker_DesignNotes.md`.

**Ориентация:** горизонтальная, радиальная (ось ролика направлена к центру платформы) — ролик стоит «диском» и катится верхней точкой по нижней поверхности подвижной платформы, как в классической схеме lazy susan.

**Опора — пилон (боббыш) на кольцевой полке основания, ось консольная:**

| Участок оси (от стенки пилона наружу) | Длина, мм | Диаметр |
|---|---|---|
| Асимметричный переходной прилив (плоский срез сверху вровень с платформой, свободное расширение вниз/в стороны, угол ~40-45°, база ∅10-12 мм) | 3.0–4.0 | переменный |
| Посадка ролика 625ZZ | 5.0 | ∅5.0 (печать 4.9) |
| Канавка под стопорное кольцо (впритык к подшипнику, без зазора — кольцо слегка поджимает торец, устраняя осевой люфт) | 0.6 | ∅4.6–4.7 (E-clip DIN 6799 на вал 5 мм) |
| Хвостовик под колпачок | 1.5 | ∅4.8 |
| Монтажный зазор за концом оси (для манёвра подшипником OD16 при надевании сбоку) | 6.0 | — |

- Центр оси — **на 3.2 мм ниже** верхней плоскости платформы/пилона (ограничено тем, что вал растёт из платформы, не выше её уровня)
- Выступ ролика над платформой: **H ≈ 4.8 мм** (зазор между плитами 1.5 мм + канавка проседания подвижной платформы 3 мм + допуск печати 0.3 мм)

**Вырез (паз) в пилоне:**
- Ширина тангенциально (по кругу): 18 мм (паз) / ~24 мм (габарит пилона)
- Радиальная глубина: ~14–15 мм (длина открытой части оси 8.4 мм + монтажный зазор 6 мм)
- Высота пилона: ~14–15 мм

**Колпачок (крышка выреза) — двухсоставная, разъём по горизонтали:**
- Две симметричные половины (верхняя/нижняя), каждая — полукруглый жёлоб под хвостовик оси
- В зоне стопорного кольца жёлоб сужен (∅9–10 мм) — физически не даёт E-clip (наружный ∅~11 мм) выскочить в сторону
- Крепление: 2× М2 heat-insert, стягивают половины друг с другом (+ опционально крепление к телу пилона)
- Сборка: ролик заводится на ось сбоку через монтажный зазор → ставится стопорное кольцо → половины колпачка закрывают хвостовик сверху и снизу без осевого движения вдоль оси

**Ориентировочная нагрузка на ролики:** суммарный вес всего, что несёт платформа (сама платформа + вилка + мотор возвышения + цилиндр + лазер + подшипники + провода) ≈ **1.3–1.4 кг**, то есть ~450 г на ролик при равном распределении. Динамическая грузоподъёмность 625ZZ (~300+ кг) на порядки перекрывает эту нагрузку — вопрос был не в прочности, а в точности/люфте посадки.

### Кольцевая полка / пилоны под ролики
- Заменяет прежнюю сплошную полку (радиус 70 мм, ширина 12 мм, высота 4 мм) — теперь это 3× локальных пилона высотой ~14–15 мм на том же радиусе, через 120°
- Лабиринтное уплотнение платформа↔основание — без изменений (см. исходную сводку)

### Внутренние ложементы, внешние отверстия в стенке — без изменений (см. исходную сводку)

---

## УЗЕЛ 2 — ПОВОРОТНАЯ ПЛАТФОРМА

- Диск ∅160 мм, толщина 14 мм — без изменений в габаритах
- **Канавка проседания на нижней стороне платформы (радиус 70 мм) — глубина 3 мм** (вместо прежней общей полки-ролика — теперь платформа своей канавкой садится на 3 ролика, торчащих из пилонов основания)
- Крепление к валу, крепление вилки (фланец 6×М3), канал под провода, магнит датчика Холла — без изменений (см. исходную сводку)

---

## УЗЕЛ 3 — ВИЛКА

Без изменений относительно первой версии, за исключением метода фиксации наружных колец подшипников 6001 в левой и правой стойках (см. раздел «Фиксация наружного кольца» выше — циркулярное стопорное кольцо + клей вместо уголков).

- Левая стойка: slip ring #2, подшипник 6001
- Правая стойка: мотор возвышения (NEMA17, редуктор 1:40), подшипник 6001, датчик Холла возвышения
- Горизонтальный вал возвышения — **2 подшипника** (левая + правая стойка), без изменений: консольная нагрузка от веса цилиндра требует именно двух опор, разнесённых на 120 мм. См. `StarTracker_DesignNotes.md`.

---

## УЗЕЛ 4 — ЦИЛИНДР

Без изменений относительно первой версии, за исключением метода фиксации наружных колец подшипников 6001 (передний торец, задняя крышка) — циркулярное стопорное кольцо + клей вместо уголков/диска.

- Вал цилиндра — **2 подшипника** (передний торец + задняя крышка), без изменений: та же логика консольной нагрузки, база ~132 мм.

---

## ПОДШИПНИКИ И СТАНДАРТНЫЕ ДЕТАЛИ (обновлено)

| Деталь | Тип | Кол-во | Где |
|---|---|---|---|
| Подшипник 6001 | ∅28/∅12×8 мм | 5 | 1× верхняя стенка основания, 2× стойки вилки, 2× цилиндр (торец+крышка) |
| **Подшипник 625ZZ** | **∅16/∅5×5 мм** | **3** | **Ролики поворотной платформы (было 6× 623ZZ)** |
| Slip ring 12 мм | ∅12/∅22/L30 мм | 2 | #1 основание, #2 левая стойка |
| Магнит | ∅6×3 мм | 2 | Червячное колесо азимута, задняя крышка цилиндра |
| **Стопорное кольцо DIN 472 (бор ∅28)** | ГОСТ 13943-86 | 5 | Фиксация наружных колец всех 6001 |
| **Стопорное кольцо E-clip (вал ∅5)** | DIN 6799 | 3 | Фиксация внутренних колец роликов 625ZZ |
| Heat-insert М3 | стандартные | ~24 шт | Разъёмные соединения (кроме роликового узла) |
| Heat-insert М2 | стандартные | ~18 шт | Платы, колпачки роликов |
| ~~Уголки стопорные~~ | ~~отдельный файл~~ | ~~0~~ | **Исключены из проекта, заменены стопорными кольцами** |

---

## ЭЛЕКТРОНИКА — РАЗМЕЩЕНИЕ

Без изменений относительно первой версии (см. исходную сводку) — ESP32, TMC2209×2, DC-DC, BMS, АКБ, GPS, IMU, RTC, датчики Холла — всё в основании и вилке/цилиндре как было расписано.

---

## ФАЙЛОВАЯ СТРУКТУРА SOLIDWORKS (обновлена)

```
StarTracker.sldasm
├── Base_Body.sldprt
├── RotaryPlatform.sldprt
├── RollerPylon.sldprt           ← новая деталь (×3, либо влита в Base_Body)
├── RollerAxle_625ZZ.sldprt      ← новая деталь (вместо оси на винте)
├── RollerCap_Upper.sldprt       ← новая деталь
├── RollerCap_Lower.sldprt       ← новая деталь
├── Fork_Left.sldprt
├── Fork_Right.sldprt
├── Fork_Crossbar.sldprt
├── Fork_Flange.sldprt
├── Drum_Body.sldprt
├── Drum_RearCap.sldprt
├── Shaft_Vertical.sldprt
├── Shaft_Horizontal.sldprt
├── WormWheel_Az.sldprt
├── WormWheel_El.sldprt
└── Hardware/ (из Toolbox)
    ├── Bearing_6001.sldprt
    ├── Bearing_625ZZ.sldprt          ← вместо Bearing_623ZZ
    ├── NEMA17.sldprt
    ├── SlipRing_12mm.sldprt
    ├── CirclipDIN472_28mm.sldprt     ← новая (бор, для 6001)
    └── CirclipE_5mm.sldprt           ← новая (вал, для 625ZZ)
```

*(файлы `Bracket_Corner.sldprt` и `Bracket_Disk.sldprt` исключены из структуры)*

---

## ИТОГОВЫЕ ГАБАРИТЫ

Без изменений относительно первой версии — переработка роликового узла не повлияла на общие габариты устройства (кольцевая полка/пилоны остаются в пределах прежнего диаметра основания ∅160 мм).

| Параметр | Размер |
|---|---|
| Диаметр основания | ∅160 мм |
| Высота основания | 105 мм |
| Высота поворотной платформы | 14 мм |
| Высота вилки | 100 мм |
| Диаметр цилиндра | ∅110 мм |
| Длина цилиндра | 140 мм |
| Полная высота устройства (лазер горизонтально) | ~280 мм |
| Ширина по вилке | 148 мм |

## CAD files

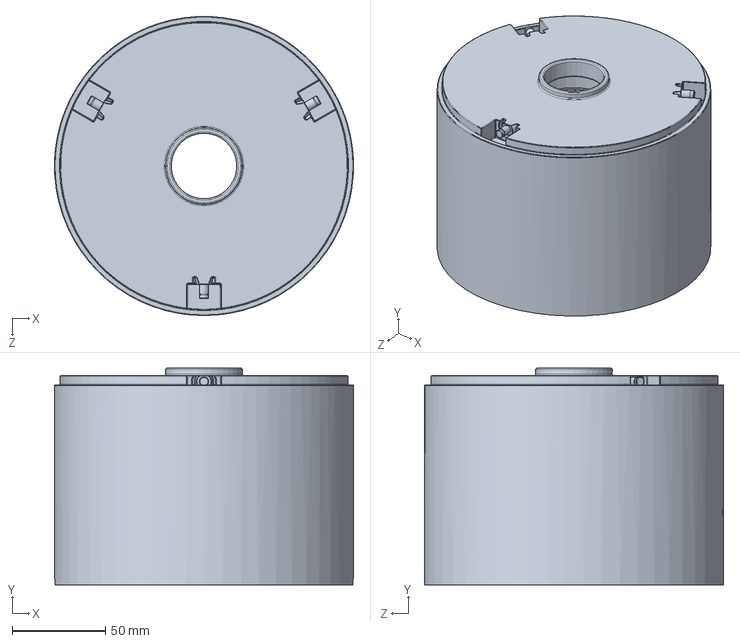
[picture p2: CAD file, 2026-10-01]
CAD/Base/Base.SLDPRT
160.0 x 116.0 x 160.0 mm

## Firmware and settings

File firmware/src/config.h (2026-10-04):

#pragma once

// ============================================================
//  ASTRA: конфигурация прошивки (ESP32)
//  Все значения ниже - заготовки. Пины -1 = не назначен.
//  Wi-Fi и токен Telegram лежат в secrets.h
// ============================================================

// ---------- Моторы (TMC2209 x2) ----------
#define MOTOR_AZ_STEP_PIN        -1
#define MOTOR_AZ_DIR_PIN         -1
#define MOTOR_AZ_EN_PIN          -1

#define MOTOR_ALT_STEP_PIN       -1
#define MOTOR_ALT_DIR_PIN        -1
#define MOTOR_ALT_EN_PIN         -1

// Направление вращения: 1 или -1 (инверсия, если ось крутится не туда)
#define MOTOR_AZ_DIR_SIGN        0
#define MOTOR_ALT_DIR_SIGN       0

// Механика: шагов на оборот мотора, микрошаг, редукция до оси
#define MOTOR_STEPS_PER_REV      0
#define MOTOR_MICROSTEPS         0
#define MOTOR_AZ_GEAR_RATIO      0
#define MOTOR_ALT_GEAR_RATIO     0

// Динамика (шагов/с и шагов/с^2)
#define MOTOR_MAX_SPEED          0
#define MOTOR_ACCEL              0

// Допуск «цель достигнута», градусы
#define MOTOR_TARGET_TOLERANCE_DEG  0

// ---------- Поиск нуля (датчики Холла A3144E) ----------
#define HALL_AZ_PIN              -1
#define HALL_ALT_PIN             -1
#define HALL_ACTIVE_LEVEL        0      // 0 или 1: уровень при срабатывании

#define HOMING_SPEED             0      // шагов/с
#define HOMING_TIMEOUT_MS        0

// Угол оси в момент срабатывания Холла (в системе монтировки, градусы)
#define HOME_AZ_OFFSET_DEG       0
#define HOME_ALT_OFFSET_DEG      0

// ---------- Лазер ----------
#define LASER_PIN                -1
#define LASER_ACTIVE_LEVEL       0      // 0 или 1
#define LASER_MAX_ON_MS          0      // автоотключение

// ---------- I2C (IMU, магнитометр, RTC) ----------
#define I2C_PORT                 0
#define I2C_SDA_PIN              -1
#define I2C_SCL_PIN              -1
#define I2C_FREQ_HZ              0

#define IMU_I2C_ADDR             0      // BMI160
#define MAG_I2C_ADDR             0      // GY-511 (магнитометр)
#define MAG_ACCEL_I2C_ADDR       0      // GY-511 (акселерометр)
#define RTC_I2C_ADDR             0      // DS3231

// ---------- GPS (UART) ----------
#define GPS_UART_NUM             0
#define GPS_TX_PIN               -1
#define GPS_RX_PIN               -1
#define GPS_BAUD                 0

// ---------- Компас ----------
// Магнитное склонение, градусы, + к востоку
#define MAG_DECLINATION_DEG      0.0f

// Угол между направлением az = 0 монтировки и осью X датчика, градусы
#define MAG_MOUNT_OFFSET_DEG     0.0f

// ---------- IMU ----------
// Поправки нуля наклона основания, градусы
#define IMU_ROLL_OFFSET_DEG      0.0f
#define IMU_PITCH_OFFSET_DEG     0.0f

// ---------- Логика наведения ----------
// Минимальная высота цели над горизонтом для включения лазера, градусы
#define MIN_ELEVATION_DEG        0.0f

// Периоды, мс
#define SENSORS_POLL_PERIOD_MS   0
#define TRACKING_PERIOD_MS       0

// ---------- Задачи FreeRTOS ----------
#define TASK_SENSORS_STACK       0
#define TASK_SENSORS_PRIO        0
#define TASK_MOTORS_STACK        0
#define TASK_MOTORS_PRIO         0
#define TASK_TRACKING_STACK      0
#define TASK_TRACKING_PRIO       0

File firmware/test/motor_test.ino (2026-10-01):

// Пины управления CNC Shield v3 для Arduino Uno
#define EN_PIN    8   // Пин включения всех драйверов (низкий уровень = ВКЛ)

#define X_STEP    2   // Шаг оси X
#define X_DIR     5   // Направление оси X

#define Y_STEP    3   // Шаг оси Y
#define Y_DIR     6   // Направление оси Y

void setup() {
  // Настраиваем пины на выход
  pinMode(EN_PIN, OUTPUT);
  pinMode(X_STEP, OUTPUT);
  pinMode(X_DIR, OUTPUT);
  pinMode(Y_STEP, OUTPUT);
  pinMode(Y_DIR, OUTPUT);
  
  // Включаем драйверы (подаем LOW)
  digitalWrite(EN_PIN, LOW); 
  
  delay(1000); // Пауза 1 секунда перед стартом движений

  // --- ТЕСТ ОСИ X ---
  digitalWrite(X_DIR, HIGH); // Направление 1
  for(int i = 0; i < 400; i++) { // Сделать 400 микрошагов
    digitalWrite(X_STEP, HIGH);
    delayMicroseconds(800); // Скорость
    digitalWrite(X_STEP, LOW);
    delayMicroseconds(800);
  }
  delay(1000); // Пауза 1 секунда
  
  digitalWrite(X_DIR, LOW);  // Направление 2 (обратно)
  for(int i = 0; i < 400; i++) {
    digitalWrite(X_STEP, HIGH);
    delayMicroseconds(800);
    digitalWrite(X_STEP, LOW);
    delayMicroseconds(800);
  }
  delay(1000); // Пауза 1 секунда

  // --- ТЕСТ ОСИ Y ---
  digitalWrite(Y_DIR, HIGH); // Направление 1
  for(int i = 0; i < 400; i++) {
    digitalWrite(Y_STEP, HIGH);
    delayMicroseconds(800);
    digitalWrite(Y_STEP, LOW);
    delayMicroseconds(800);
  }
  delay(1000); // Пауза 1 секунда
  
  digitalWrite(Y_DIR, LOW);  // Направление 2 (обратно)
  for(int i = 0; i < 400; i++) {
    digitalWrite(Y_STEP, HIGH);
    delayMicroseconds(800);
    digitalWrite(Y_STEP, LOW);
    delayMicroseconds(800);
  }
}

void loop() {
  // Тут пусто, чтобы тест выполнился один раз до нажатия кнопки RESET
}

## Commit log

2026-10-01 Add Completed work and .gitattributes to normalize line endings
    [Основание.SLDPRT]
2026-10-01 Add current results
2026-10-04 Rename all folders and files to English
    [Base.SLDPRT]
2026-11-11 feat(handler): convert horizon coordinates to mount angles
2026-11-11 test(handler): verify mount angles and tilt compensation
2026-11-11 feat(adapter): validate sensor readings for pointing
